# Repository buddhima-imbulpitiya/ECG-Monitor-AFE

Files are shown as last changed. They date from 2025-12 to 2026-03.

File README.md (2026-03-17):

# 3-Lead ECG Monitor - AFE

A fully functional analog front end (AFE) for an electrocardiogram (ECG) monitor designed and developed using exclusively analog electronics for signal acquisition, amplification, and filtering. The device captures cardiac electrical activity through three electrodes and outputs a clean ECG waveform for real-time monitoring on an oscilloscope.

<p align=>
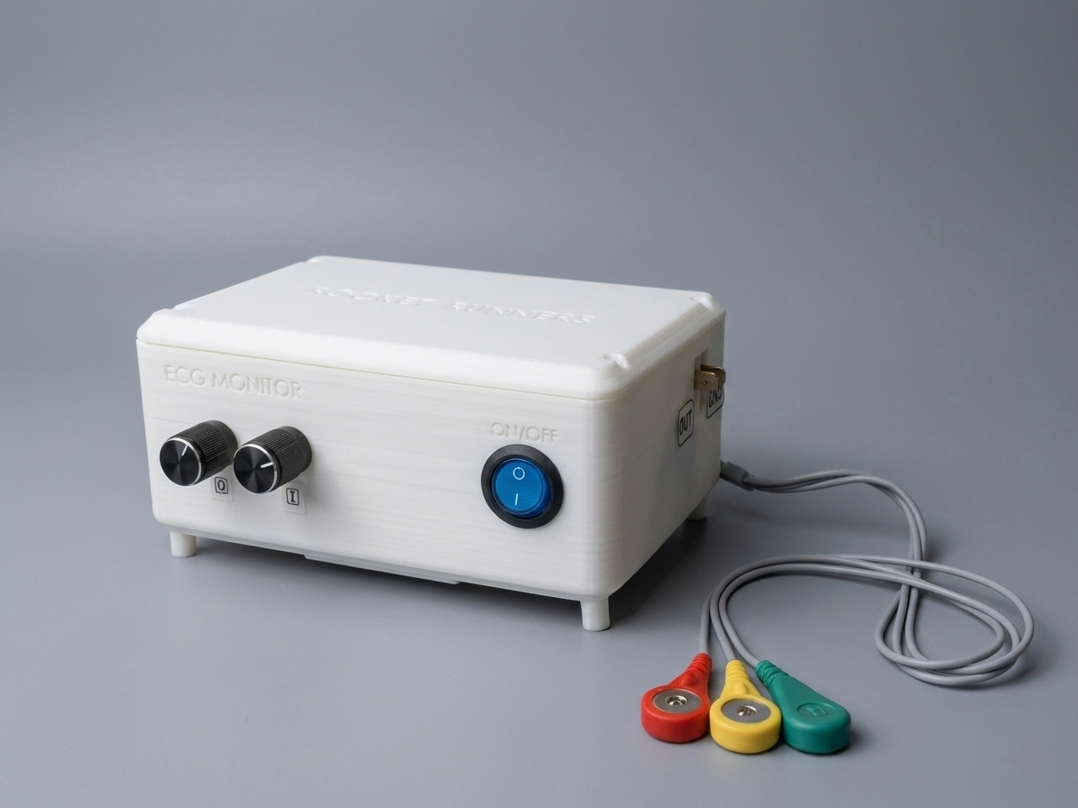
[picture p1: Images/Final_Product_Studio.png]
  
  &nbsp;&nbsp;&nbsp;&nbsp; &nbsp;&nbsp;&nbsp;&nbsp;&nbsp;&nbsp; &nbsp;&nbsp;&nbsp;&nbsp;&nbsp;&nbsp; &nbsp;&nbsp;&nbsp;&nbsp;&nbsp;&nbsp; &nbsp;&nbsp;&nbsp;
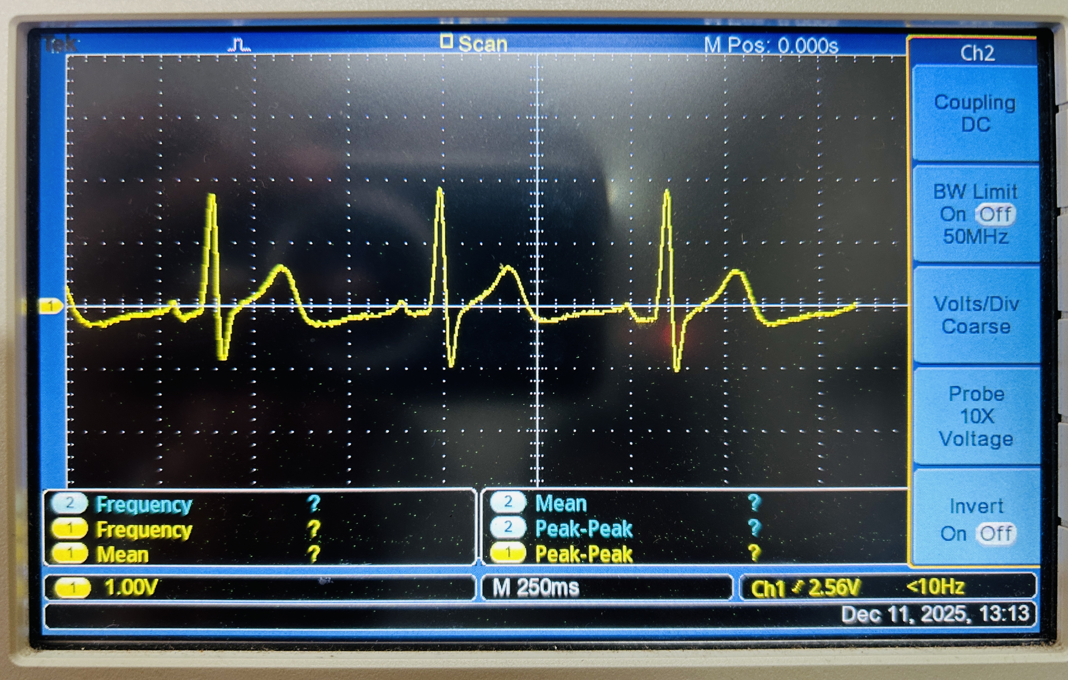
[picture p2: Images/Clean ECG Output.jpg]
  
<p/>
  
## 🔬 Overview

This project demonstrates the design and implementation of a 3-lead ECG monitoring system built entirely with analog components. The device safely extracts weak bioelectric signals from the human body (10 μV to 5 mV), amplifies them, and filters noise to produce a diagnostic-quality ECG waveform suitable for cardiac monitoring.

### Key Specifications

- **Signal Range**: 10 μV - 5 mV input amplitude
- **Frequency Range**: 0.5 Hz - 100 Hz (cardiac signal bandwidth)
- **Electrode Configuration**: 3-lead setup (LA, RA, RL) following Einthoven's Triangle (Lead-I)
- **Power Supply**: Battery-operated (dual 7.4V Li-Ion) for minimal powerline interference
- **Output**: Analog signal for oscilloscope display

## ✨ Features

- **High-Precision Instrumentation Amplifier**: OP07-based differential amplifier with adjustable gain and excellent CMRR (120 dB)
- **Multi-Stage Filtering**:
  - 2nd Order High-Pass Butterworth Filter (0.5 Hz cutoff) - removes baseline wander
  - 4th Order Low-Pass Butterworth Filter (100 Hz cutoff) - eliminates high-frequency noise
  - Wien-Robinson Notch Filter (50 Hz) - suppresses powerline interference
- **Right Leg Drive (RLD) Circuit**: Active common-mode rejection for enhanced noise immunity
- **Safety-First Design**: Battery-powered operation ensures patient safety
- **Custom PCB**: Professional PCB layout optimized for low-noise analog signal processing
- **3D-Printed Enclosure**: Ergonomic, portable design with proper electrode connections

### Signal Processing Stages

1. **Instrumentation Amplifier**: Extracts differential voltage between LA and RA electrodes with variable gain
2. **High-Pass Filter**: Removes DC offset and baseline wander (fc = 0.589 Hz)
3. **Low-Pass Filter**: Eliminates muscle artifacts and high-frequency interference (fc = 100 Hz)
4. **Notch Filter**: Attenuates 50 Hz powerline noise (fc = 49.8 Hz, Q = 0.67)
5. **Right Leg Drive**: Inverts and feeds back common-mode signals for active noise cancellation

## 🔨 Hardware Implementation

### PCB Design
- **Software**: EasyEDA
- **Type**: Through-hole components for cost effectiveness and ease of assembly
- **Layout**: 2-Layer optimized for minimal noise coupling and proper grounding

<p align=>
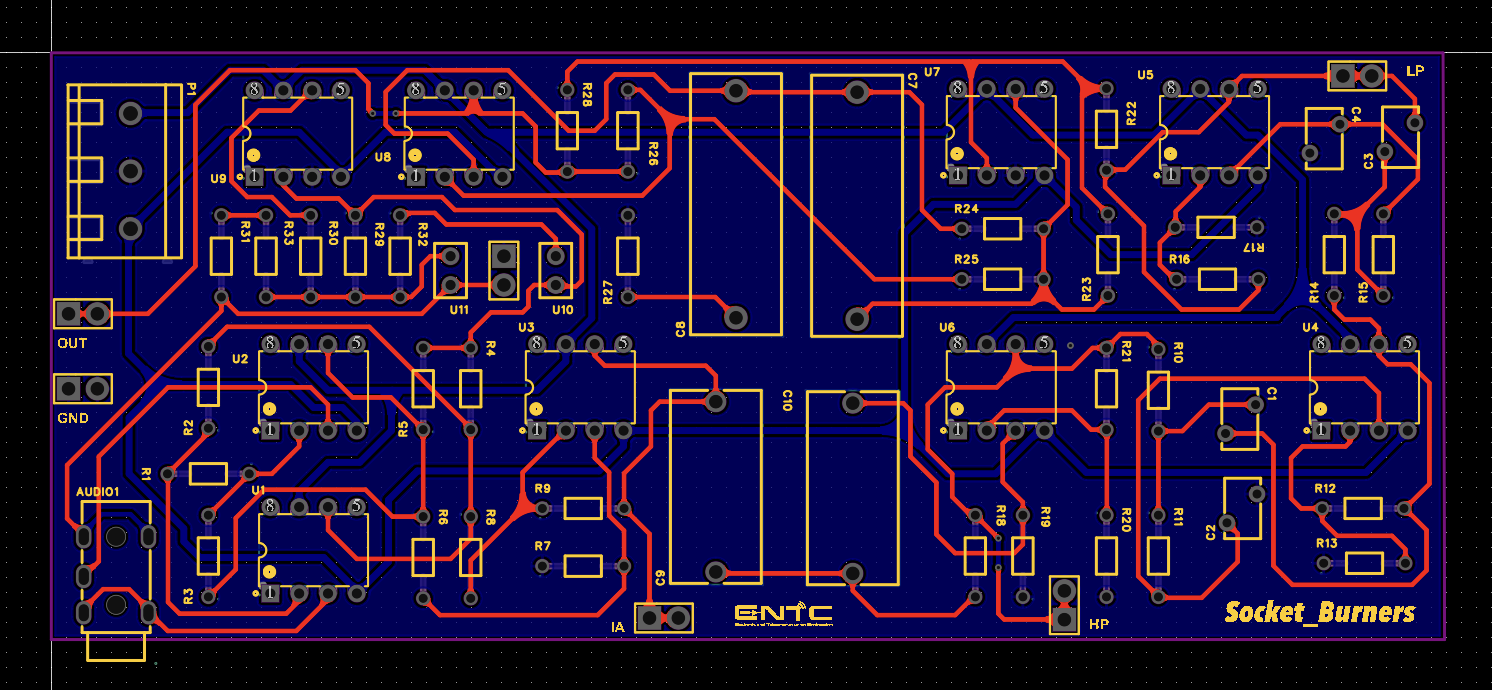
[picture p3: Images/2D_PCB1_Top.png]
  
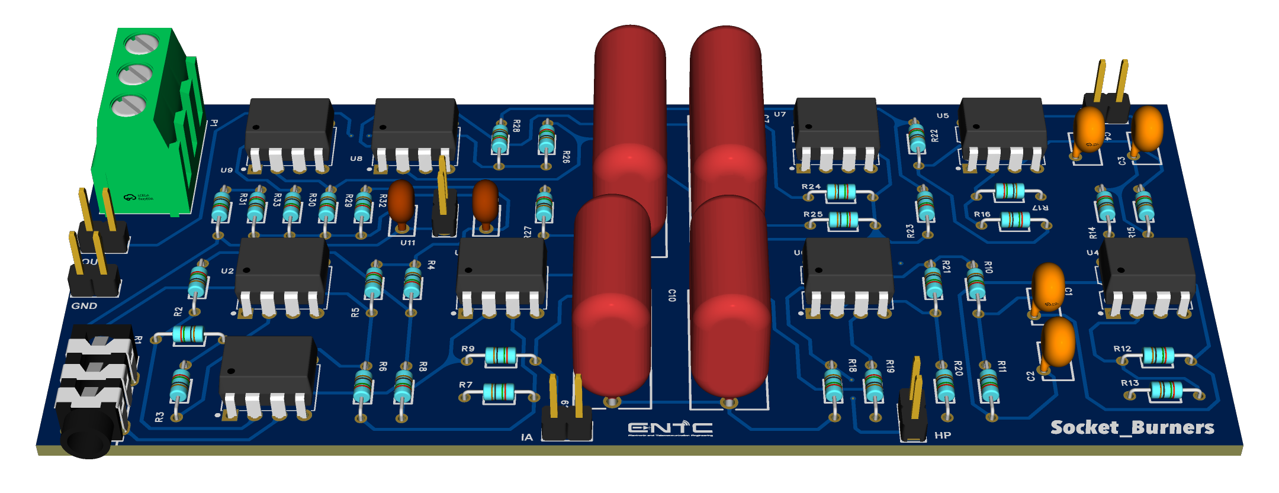
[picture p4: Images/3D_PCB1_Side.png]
  
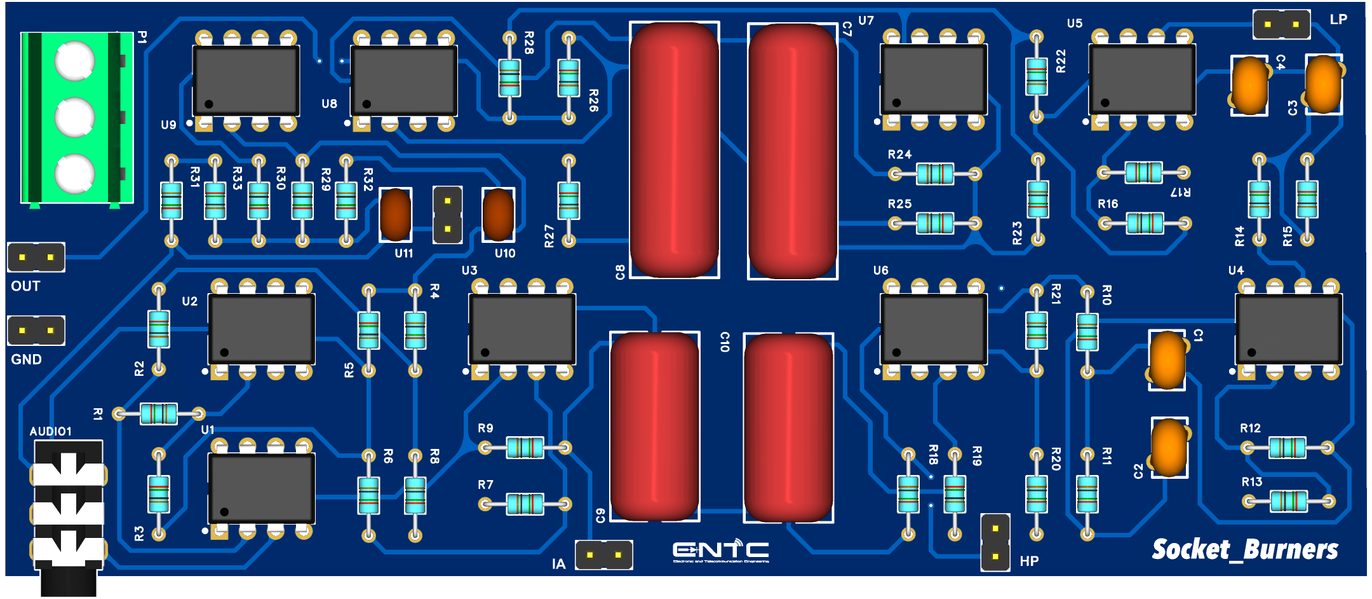
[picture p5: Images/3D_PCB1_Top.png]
   
<p/>
  
### Enclosure
- **Manufacturing**: 3D printed
- **Design**: Custom enclosure with cutouts for:
  - Output probes
  - Power switch
  - ECG leads
  - Potentiometer access for gain adjustment
    
 <p align=>
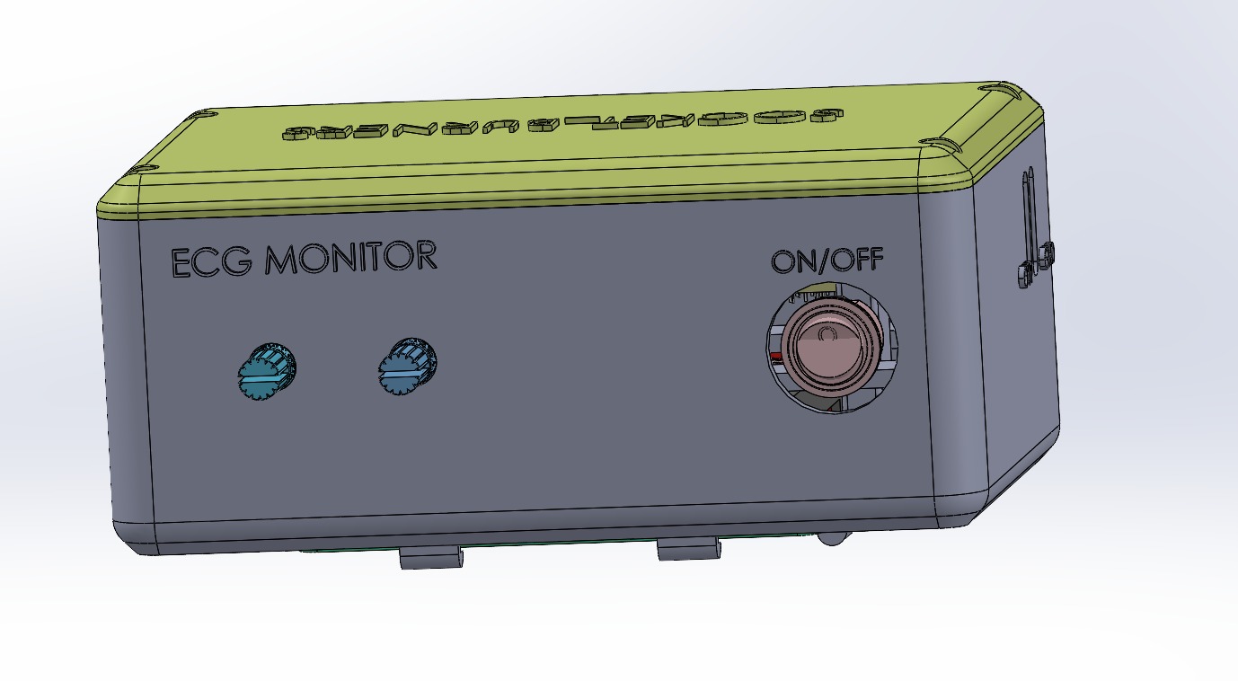
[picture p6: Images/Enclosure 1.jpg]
  
   &nbsp;&nbsp;&nbsp;&nbsp;
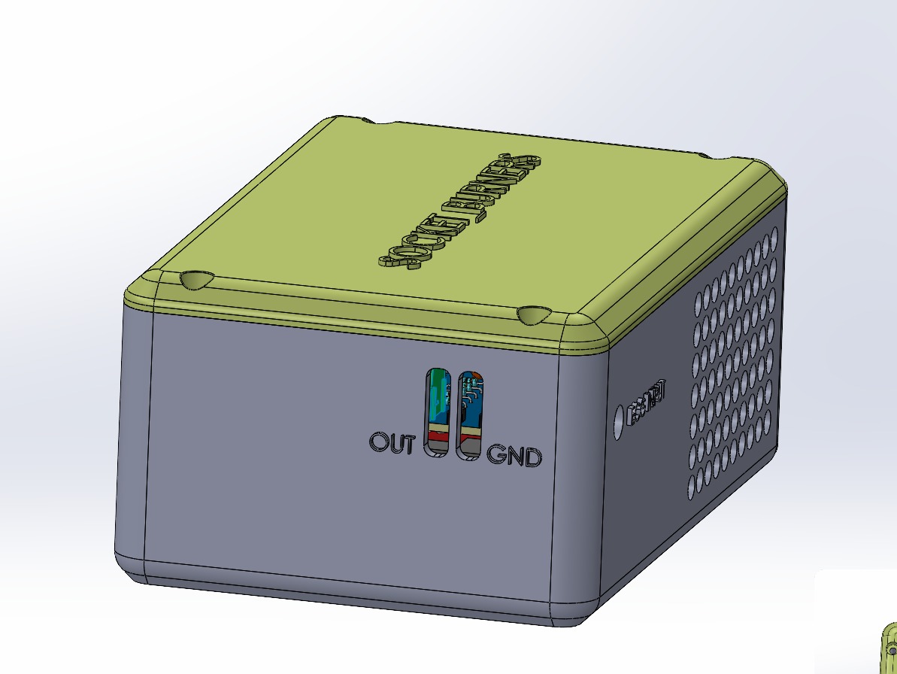
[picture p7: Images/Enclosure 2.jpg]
  
   &nbsp;&nbsp;&nbsp;&nbsp;
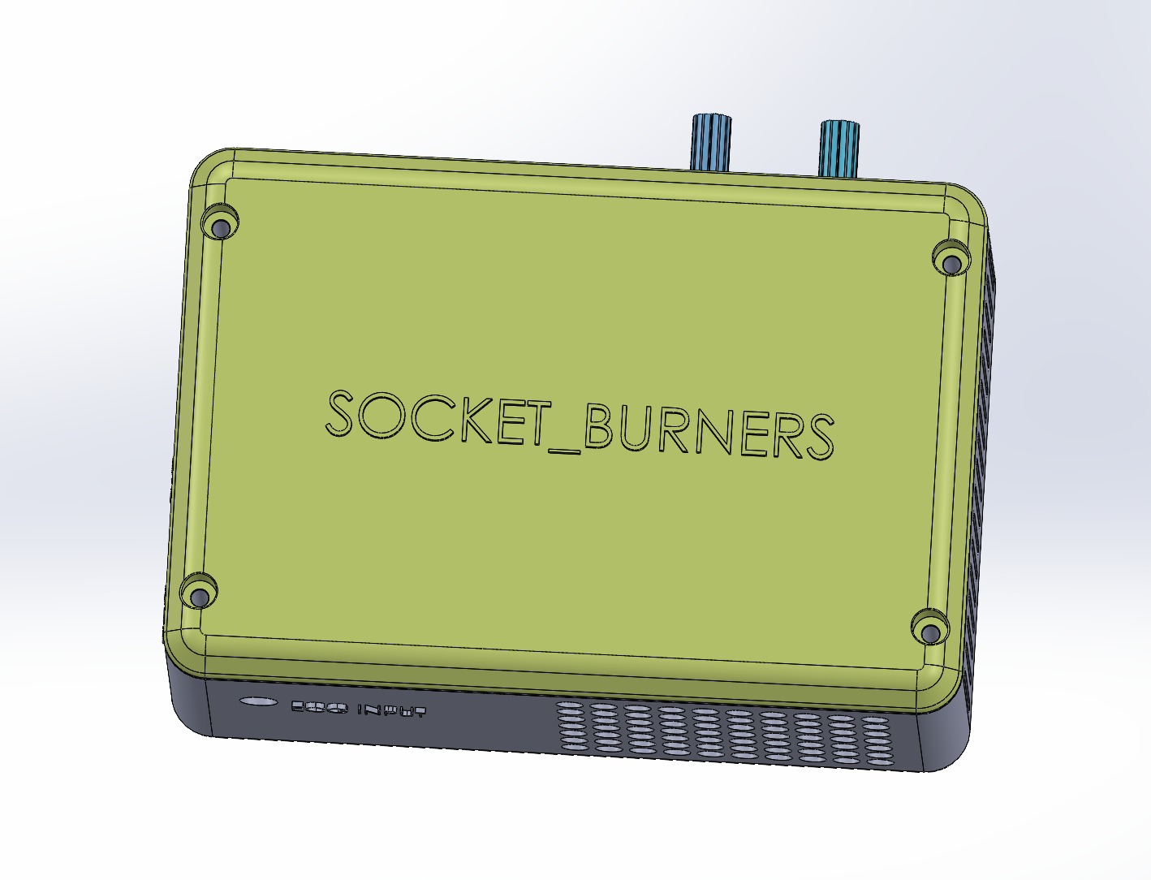
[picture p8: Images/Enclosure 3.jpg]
   
<p/>

## 📊 Testing Results

### Breadboard Prototype
- ✅ Successfully captured function generator ECG signals
- ✅ Verified with real human ECG signals
- ✅ Clean waveform with identifiable P, QRS, and T waves

<p align=>
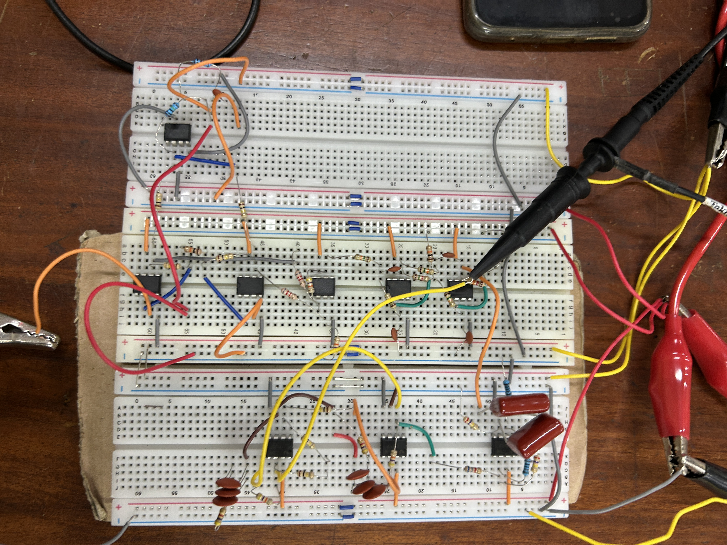
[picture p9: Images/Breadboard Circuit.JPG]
  
 &nbsp;&nbsp;&nbsp;
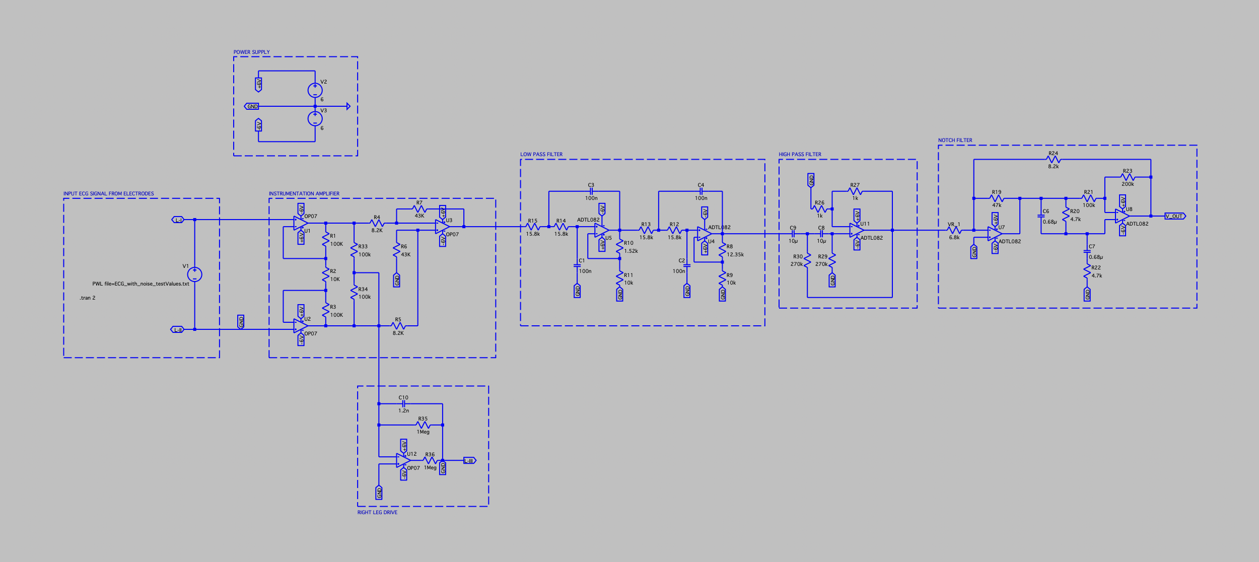
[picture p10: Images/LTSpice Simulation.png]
  
<p/>
<p align=>
  <em>Input ECG Waveform :</em>
  <br/>
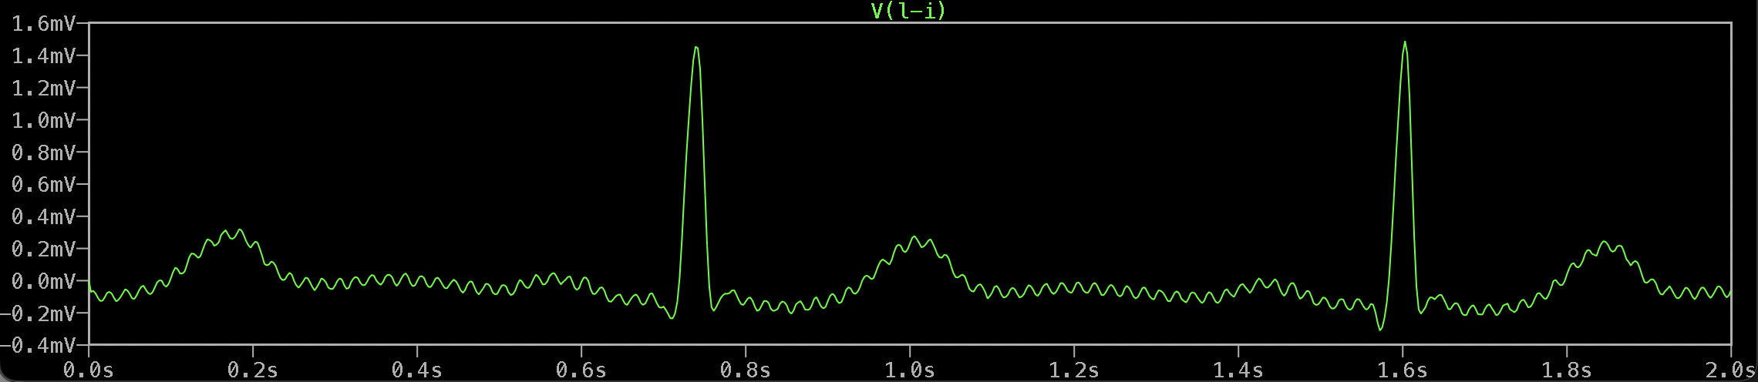
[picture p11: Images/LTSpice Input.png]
  

  <em>Output ECG Waveform :</em>
  <br/>
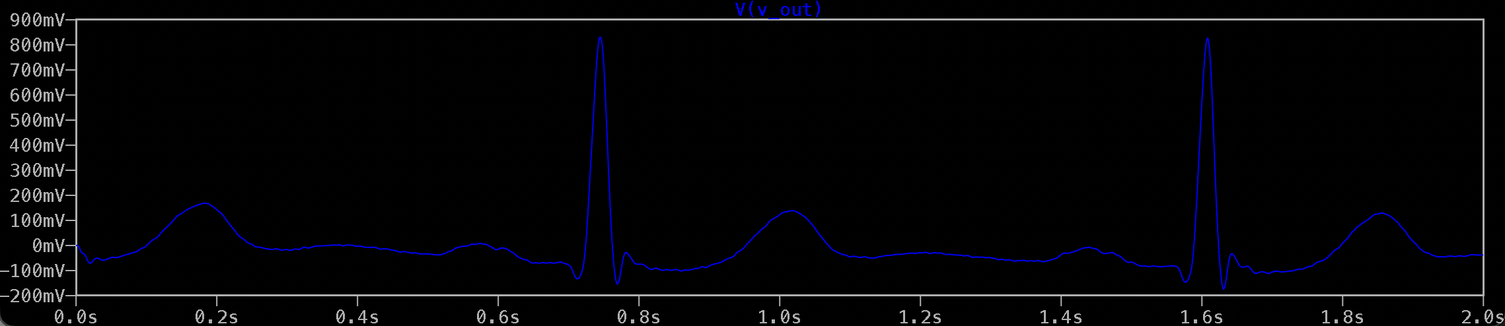
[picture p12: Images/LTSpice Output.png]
  

  <em>Overall Frequency Response :</em>
  <br/>
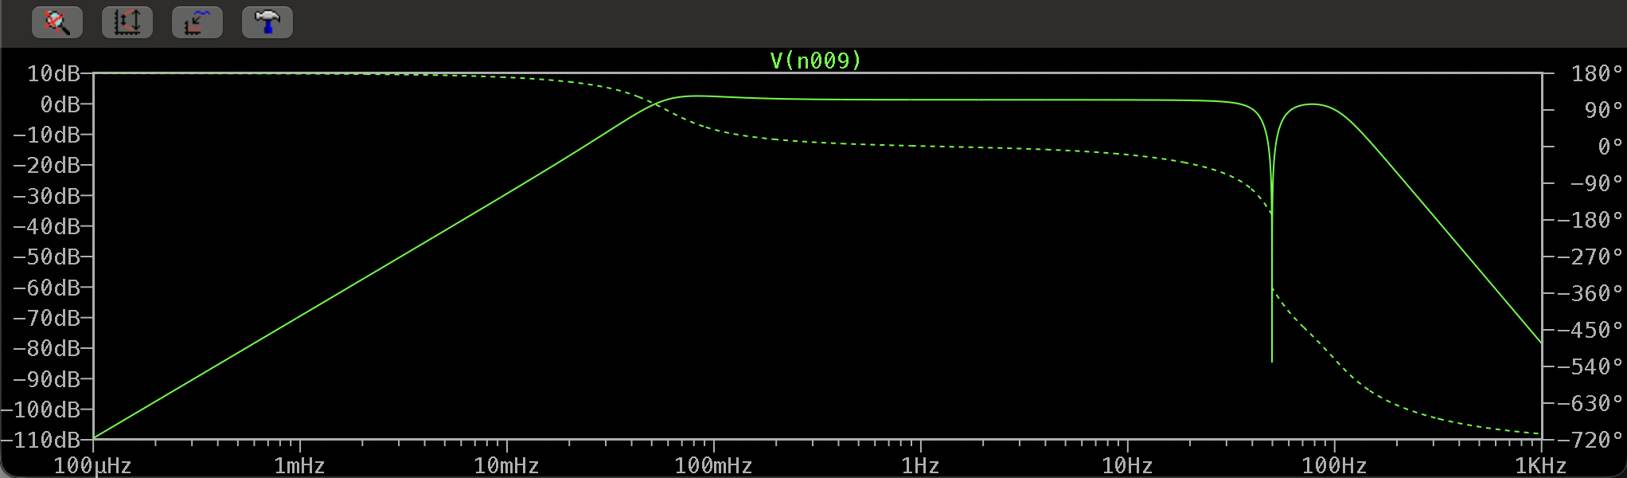
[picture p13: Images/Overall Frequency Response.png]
  

<p/>

### Final PCB Device
- ✅ Improved signal quality over breadboard implementation
- ✅ Reduced noise and interference
- ✅ Portable and user-friendly operation

<p align=>
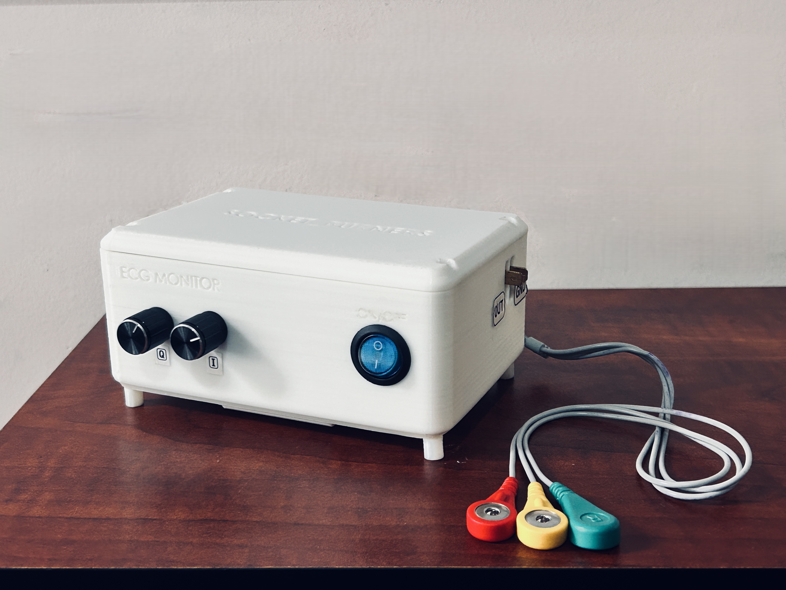
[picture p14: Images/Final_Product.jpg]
  
 &nbsp;&nbsp;&nbsp;&nbsp;&nbsp;&nbsp;&nbsp;&nbsp;&nbsp;&nbsp;&nbsp;&nbsp;&nbsp;&nbsp;&nbsp;&nbsp;&nbsp;&nbsp;&nbsp;&nbsp;&nbsp;&nbsp;&nbsp;&nbsp;&nbsp;&nbsp;&nbsp;&nbsp;
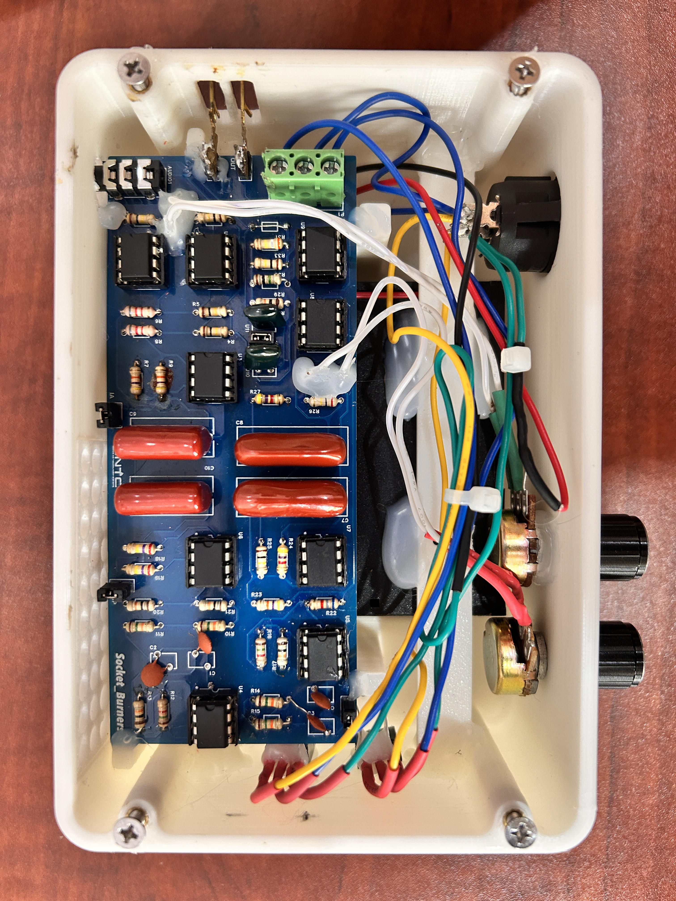
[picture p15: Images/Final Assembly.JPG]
  
<p/>

## 📁 Repository Structure

```
├── schematics/              # Circuit diagrams and design files
├── simulations/             # LTspice simulation files and results
├── pcb_design/              # KiCAD/Altium files, Gerber files, BoM
├── enclosure_design/        # 3D CAD models (.STL, .STEP files)
├── documentation/           # Project report, datasheets, calculations
├── testing/                 # Test results, oscilloscope captures
└── README.md               # This file
```

## 🚀 Getting Started

### Prerequisites
- PCB fabrication service (or equipment)
- Soldering equipment
- 3D printer (for enclosure)
- Standard ECG electrodes with 3.5mm connectors
- Oscilloscope for signal visualization
- 7.4V Li-Ion batteries (×4)

### Building the Device

1. **Clone the Repository**
   ```bash
   git clone https://github.com/yourusername/ecg-monitor.git
   cd ecg-monitor
   ```

2. **PCB Fabrication**
   - Navigate to `pcb_design/`
   - Send Gerber files to PCB manufacturer
   - Order components from BoM

3. **Assembly**
   - Solder components following the schematic
   - Test each stage individually before integration
   - Calibrate gain and notch filter potentiometers

4. **Enclosure**
   - Print enclosure from `enclosure_design/` files
   - Assemble PCB into enclosure
   - Connect battery pack and electrode leads

5. **Testing**
   - Use function generator with cardiac mode for initial testing
   - Test with real ECG signals
   - Adjust potentiometers for optimal signal quality

## 👥 Team SocketBurners

- [Buddhima Imbulpitiya](https://github.com/buddhima-imbulpitiya)
- [Oshan Imaduwage](https://github.com/oshan-imaduwage)
- [Malinda Illankoon](https://github.com/malindailankoon)
- [Manitha Ayanaja](https://github.com/ManiiAya)

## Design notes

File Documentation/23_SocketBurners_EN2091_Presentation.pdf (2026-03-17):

Introduction | Circuit Stage Design | Simulation Results | Testing Results | PCB | Enclosure

# Analog ECG Heart Monitor

# Team SocketBurners

# Analog Design Project

### University of Moratuwa

## December 13, 2025

Team SocketBurners | Analog ECG Heart Monitor | December 13, 2025 | 1 / 30

# 1 Introduction

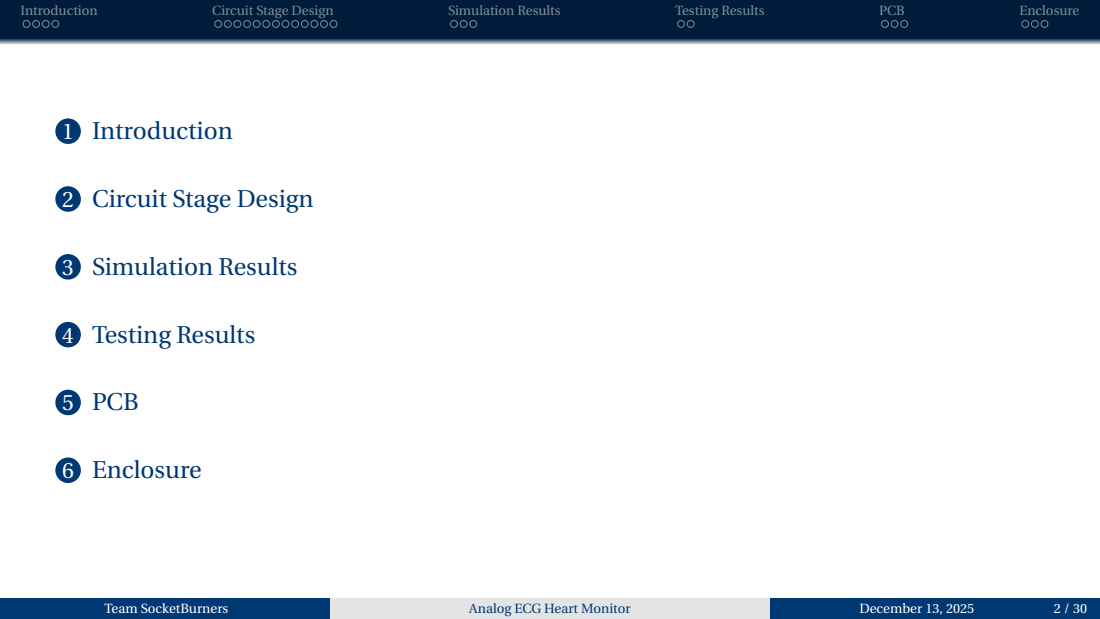
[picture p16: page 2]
3 Simulation Results; 4 Testing Results; 5 PCB; 6 Enclosure; Team SocketBurners; Analog ECG Heart Monitor; December 13, 2025

2 Circuit Stage Design

# 1 Introduction

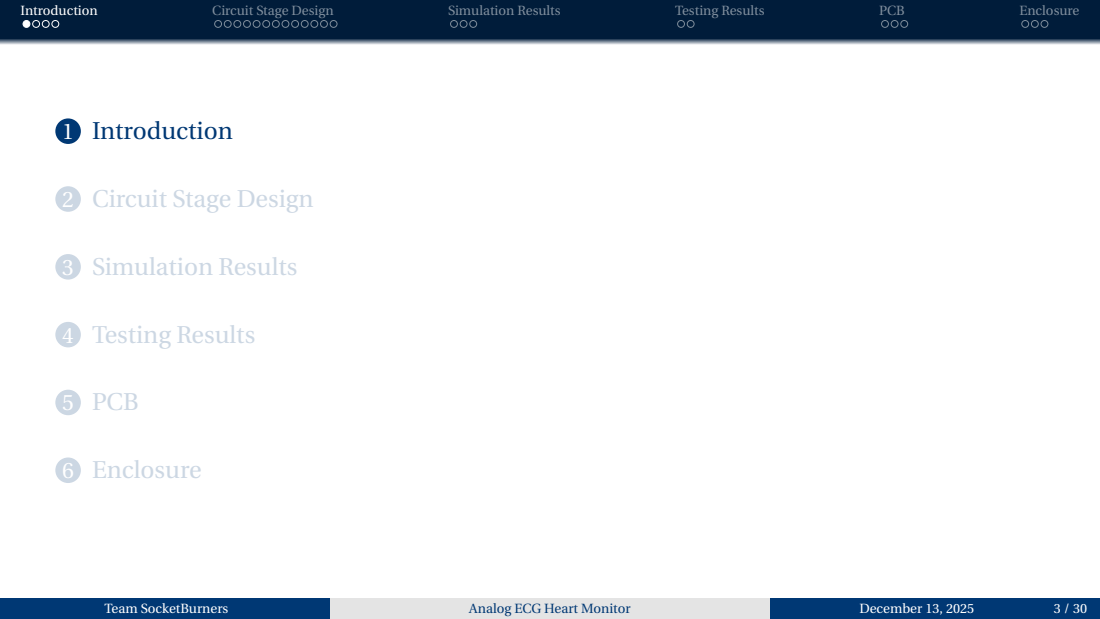
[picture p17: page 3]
3 Simulation Results; 4 Testing Results; 5 PCB; 6 Enclosure; Team SocketBurners; Analog ECG Heart Monitor; December 13, 2025

2 Circuit Stage Design

# What is an Electrocardiogram?

# - An Electrocardiogram (ECG) device is designed to display the electrical signals generated by the human cardiac system in real-time. It is a useful diagnosis tool for

many cardiac conditions.

# - The device takes inputs via 3 electrodes:

## - Left and Right Arm Electrodes (LA and RA), placed under the Left and Right clavicles - Right Leg Electrode (RL), placed on the hip or abdomen

# - The differential voltage signal between LA and RA is fed into the Instrumentation

Stage.

# - The Common Mode signal from the input is inverted and amplified via the Right

Leg Drive stage, fed back into the RL electrode.

# - The device must cleanly filter out noise and interference, without distorting the

biosignal input.

Team SocketBurners | Analog ECG Heart Monitor | December 13, 2025 | 4 / 30

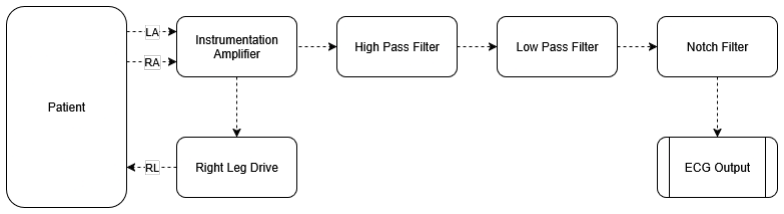
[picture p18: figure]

## Figure 1: Proposed System Architecture

Team SocketBurners | Analog ECG Heart Monitor | December 13, 2025 | 5 / 30

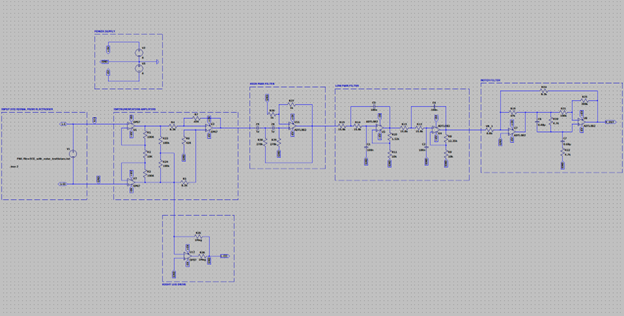
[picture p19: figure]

## Figure 2: Full Circuit Design (LTSpice Model)

Team SocketBurners | Analog ECG Heart Monitor | December 13, 2025 | 6 / 30

# 1 Introduction

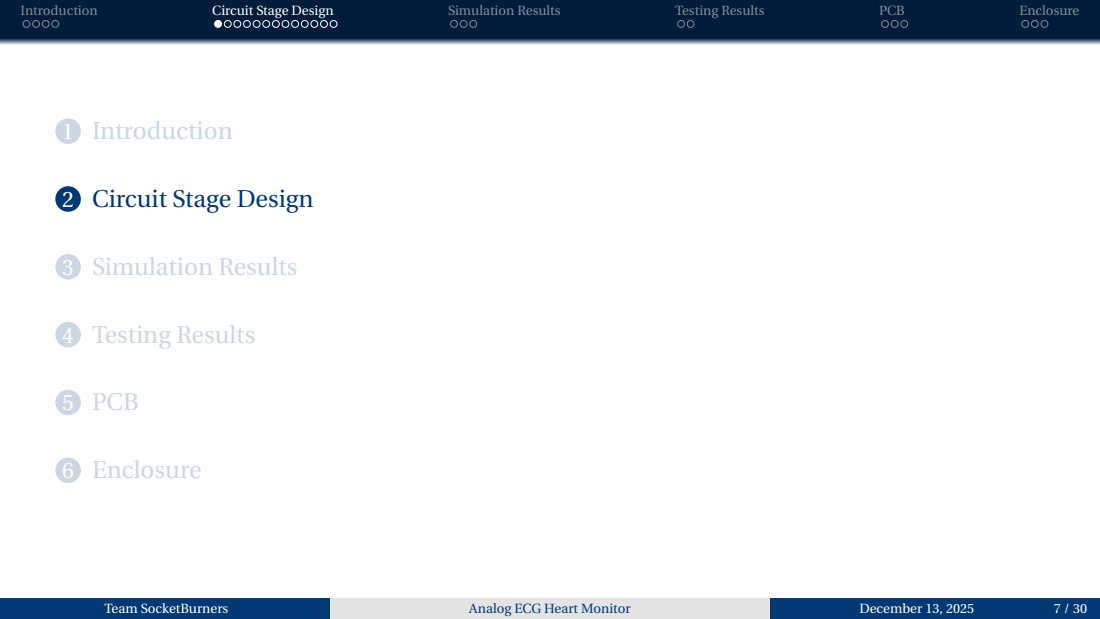
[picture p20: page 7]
3 Simulation Results; 4 Testing Results; 5 PCB; 6 Enclosure; Team SocketBurners; Analog ECG Heart Monitor; December 13, 2025

2 Circuit Stage Design

# The instrumentation amplifier extracts the differential voltage between two electrodes (LA and RA), and rejects any common-mode signals

such as noise or interference.

Av = (1+

2R

## Rgain

)×

R9
R4

# A potentiometer is used at R2 to allow for

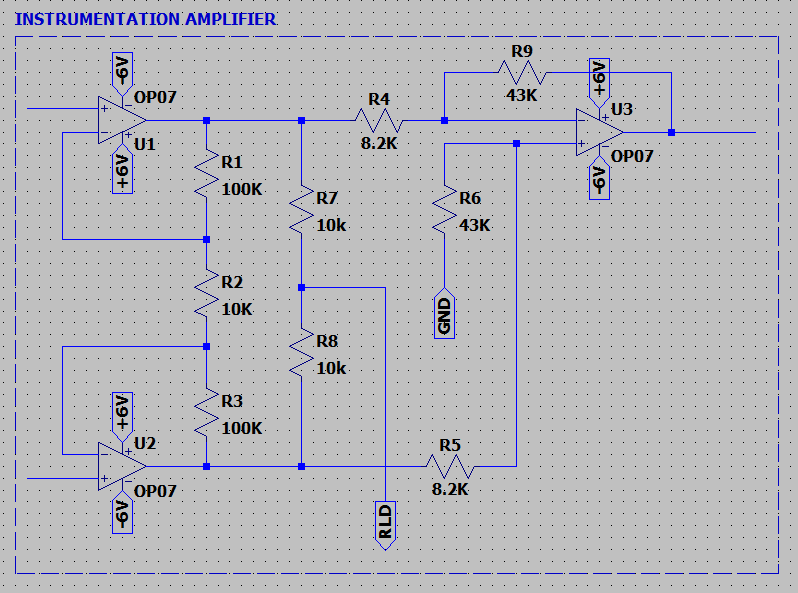
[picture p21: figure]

adjusting the gain. | Figure 3: Instrumentation Amplifier
| LTSpice Model
Team SocketBurners | Analog ECG Heart Monitor | December 13, 2025 | 8 / 30

# The High Pass Filter is used to remove baseline wander and low-frequency noise from the ECG signal. A 2nd-order Butterworth configuration was used, governed by the following equations:

# Cutoff Frequency: fc =

1
2π

p

# R1R2C1C2

(1)

# Gain: Av = 1+

R1
R2

(2)

# These relationships determine the cutoff frequency and voltage gain based on resistor and capacitor values. A cutoff around 0.5 Hz was targeted to minimize baseline drift

while preserving ECG signal components.

Team SocketBurners | Analog ECG Heart Monitor | December 13, 2025 | 9 / 30

## Using R3 = R2 = 1 kΩ, C1 = C2 = 1µF

fc =

1
2π

p

## R1R2C1C2

=

1
2π

√

## 270 kΩ×270 kΩ×1µF×1µF

= 0.589Hz

## Using R1 = R2 = 1 kΩ, C1 = C2 = 1µF

Av = 1+

R1
R2
= 1+

1 kΩ
1 kΩ

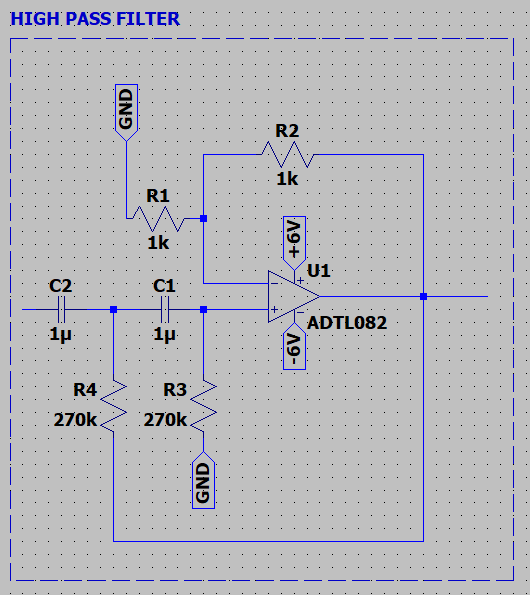
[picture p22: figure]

= 2 | Figure 4: High Pass Filter Simulation
Team SocketBurners | Analog ECG Heart Monitor | December 13, 2025 | 10 / 30

# The Low Pass Filter is used to remove unwanted high-frequency components caused by muscle artifacts and interference. A 4th-order Butterworth response was implemented using cascaded SallenKey stages. The governing setup equations are:

# Cutoff frequency: fc =

1

# 2πRC

# Closed-loop gain: Av = 1+

R1
R2

# Q-factor: Q =

1
3−K
Team SocketBurners | Analog ECG Heart Monitor | December 13, 2025 | 11 / 30

### Cutoff Frequency:

Using R = 15.8 kΩ, C = 100nF;

fc =

1

### 2πRC

=

1

### 2π×15.8 kΩ×100nF = 100.73Hz (≈ 100Hz)

### Gain Constants:

Using Rref = 10 kΩ;

K1 = 1+

R2

Rref

= 1+

1.52 kΩ
10 kΩ

= 1.152

K2 = 1+

R1

Rref

= 1+

12.35 kΩ
10 kΩ

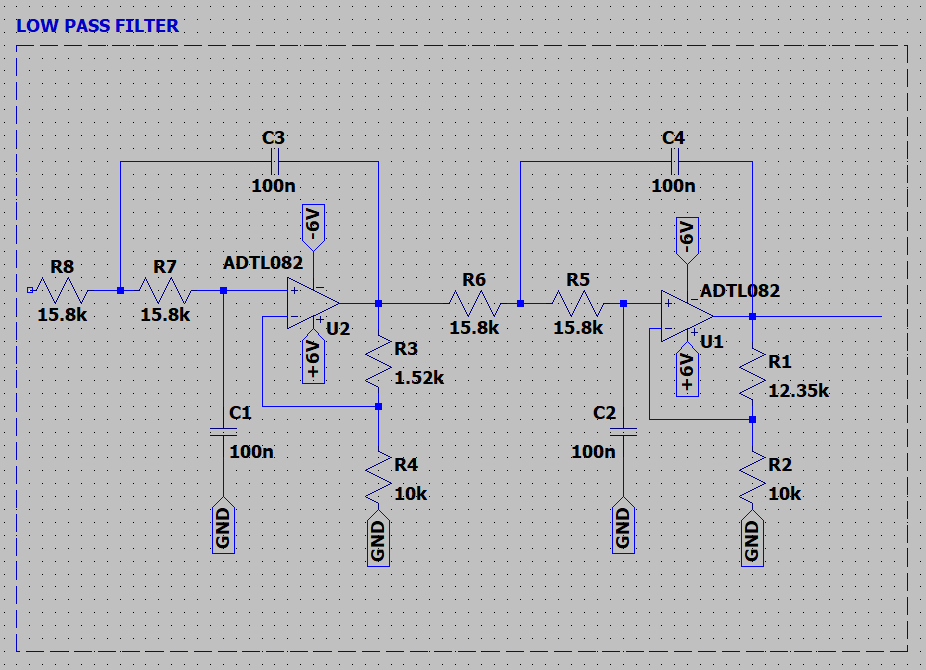
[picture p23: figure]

= 2.235 | Figure 5: Low-Pass Filter Simulation.
Team SocketBurners | Analog ECG Heart Monitor | December 13, 2025 | 12 / 30

## Using Q =

1
3−K

,

Q1 =

1
3−1.152
= 0.5411

Q2 =

1
3−2.235
= 1.307

## Table 1: Standard K-Values for Butterworth Filters

Order | K
2 | 1.586
4 | 1.152, 2.235
6 | 1.068, 1.586, 2.483
8 | 1.038, 1.337, 1.889, 2.610
Team SocketBurners | Analog ECG Heart Monitor | December 13, 2025 | 13 / 30

The Notch Filter is used to filter out the 50 Hz (or 60 Hz) mains interference and improve

# ECG SNR. A WienRobinson topology was chosen. The governing equations are:

# Cutoff frequency: fc =

1

# 2πRC

(3)

# Q-factor: Q =

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
# Gain: Av = −

R1
R2

·

1
3Q

(5)

Team SocketBurners | Analog ECG Heart Monitor | December 13, 2025 | 14 / 30

## Using R = 4.7 kΩ, C = 0.68µF

fc =

1

## 2πRC

=

1

## 2π×4.7 kΩ×0.68¸tF

= 49.8Hz

## Using R1 = 47 kΩ, R2 = 8.2 kΩ

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
47 kΩ
8.2 kΩ

)

= 2.244

Team SocketBurners | Analog ECG Heart Monitor | December 13, 2025 | 15 / 30

## Using R1 = 47 kΩ, R2 = 6.8 kΩ, Q =

2
3
Av = −

R1
R2

×

1
3Q
= −

47 kΩ
6.8 kΩ

×

1
3×2.244
= −1.02

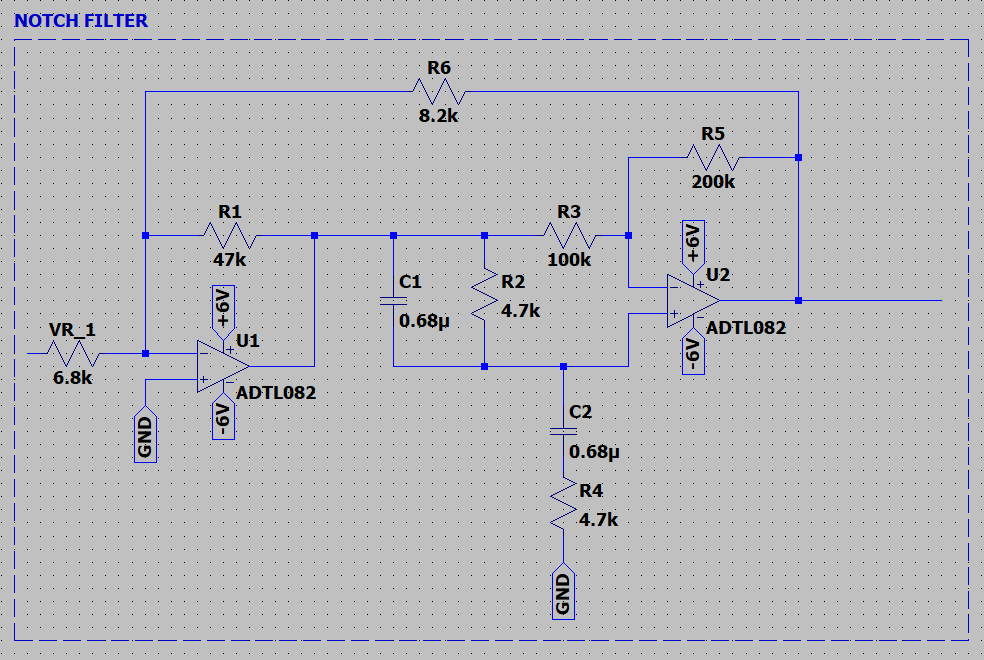
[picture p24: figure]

Figure 6: Notch Filter Simulation.

Team SocketBurners | Analog ECG Heart Monitor | December 13, 2025 | 16 / 30

# The Right Leg Drive (RLD) circuit senses the common-mode interference on the instrumentation amplifier inputs and inverts it before feeding it back into the body through the

right leg electrode.

# This feedback process effectively cancels out common-mode noise, thereby improving the Common-Mode Rejection Ratio (CMRR) of the

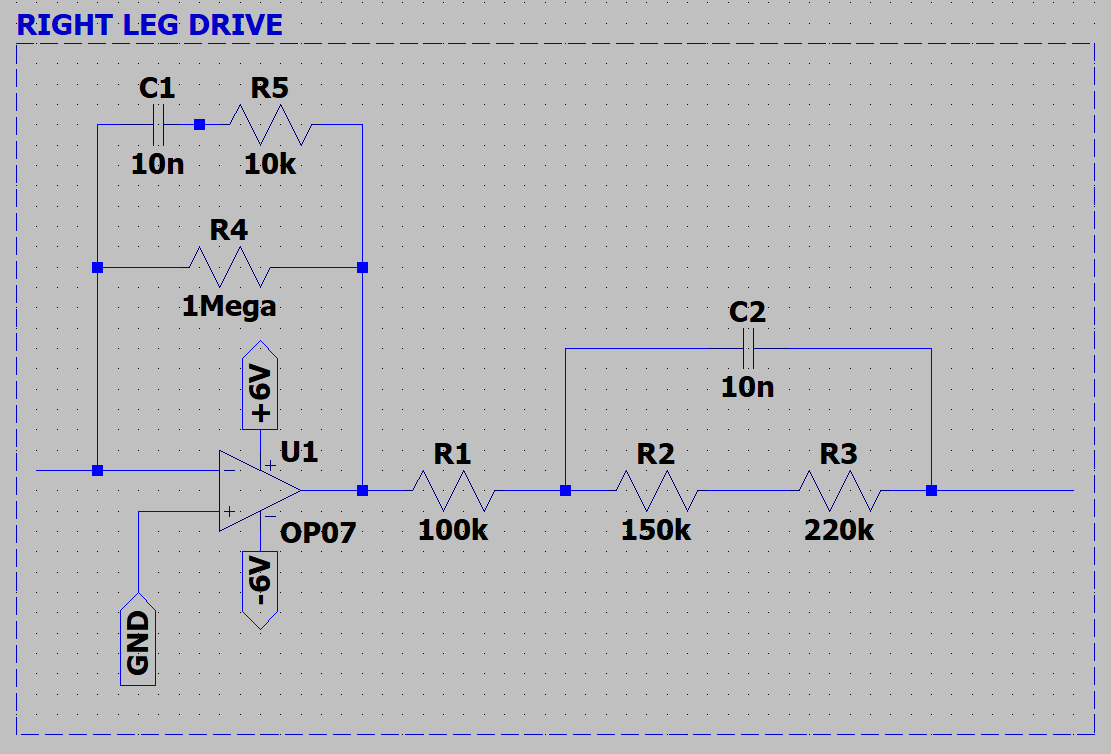
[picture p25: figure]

ECG front-end. | Figure 7: Right Leg Drive Simulation
Team SocketBurners | Analog ECG Heart Monitor | December 13, 2025 | 17 / 30

# The operational amplifiers require a split-rail power supply, generated via a simple circuit consisting of two 6 V batteries with a common

ground.

# Li-Ion batteries were chosen to reduce the impact of 50 Hz powerline noise on the received

ECG signal.

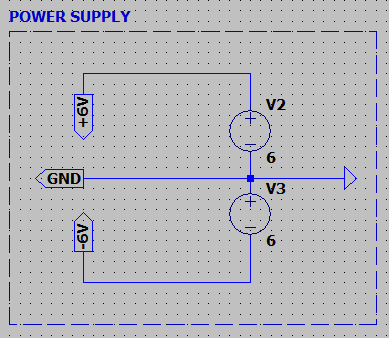
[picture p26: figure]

## Figure 8: Power Supply Simulation

Team SocketBurners | Analog ECG Heart Monitor | December 13, 2025 | 18 / 30

# In order to safely operate the device when turning on the ± Power Rails, a circuit using two

MOSFETs and a SPST switch was implemented.

# This allows for the disconnection of the two centre-tapped cells without risk of unwanted

discharging or damage to the device.

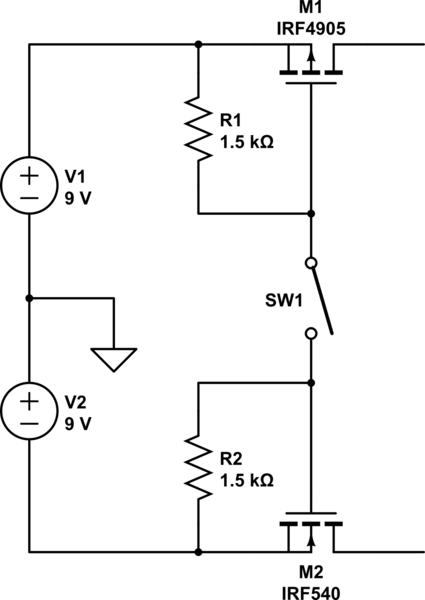
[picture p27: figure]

## Figure 9: Transistor Switch for Split Rail Power

Team SocketBurners | Analog ECG Heart Monitor | December 13, 2025 | 19 / 30

# 1 Introduction

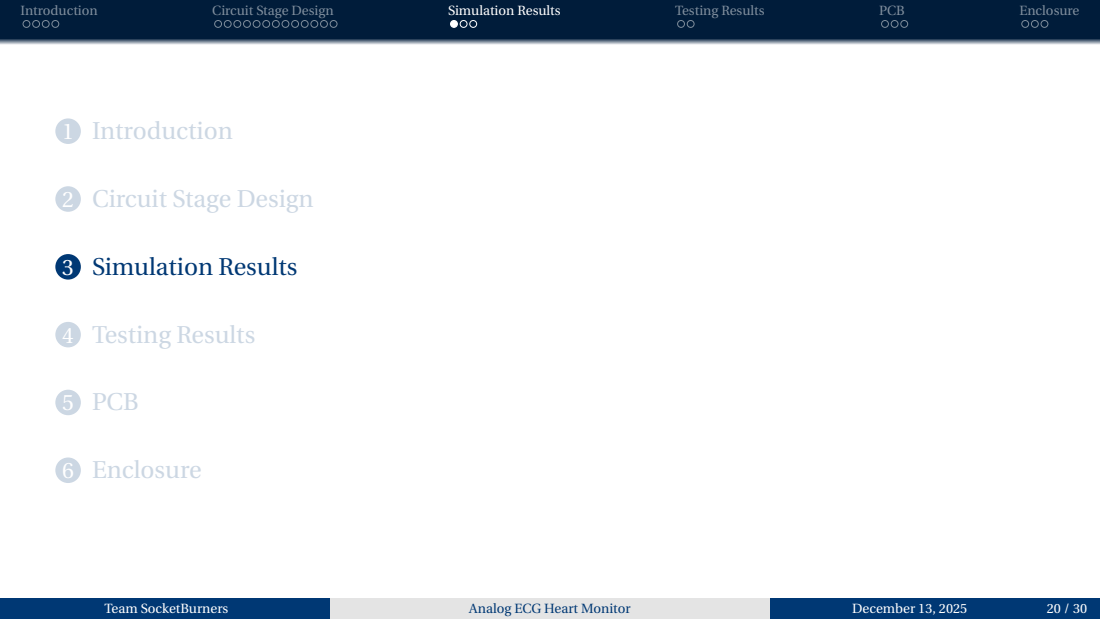
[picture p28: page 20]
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

2 Circuit Stage Design

# ECG Input vs Output

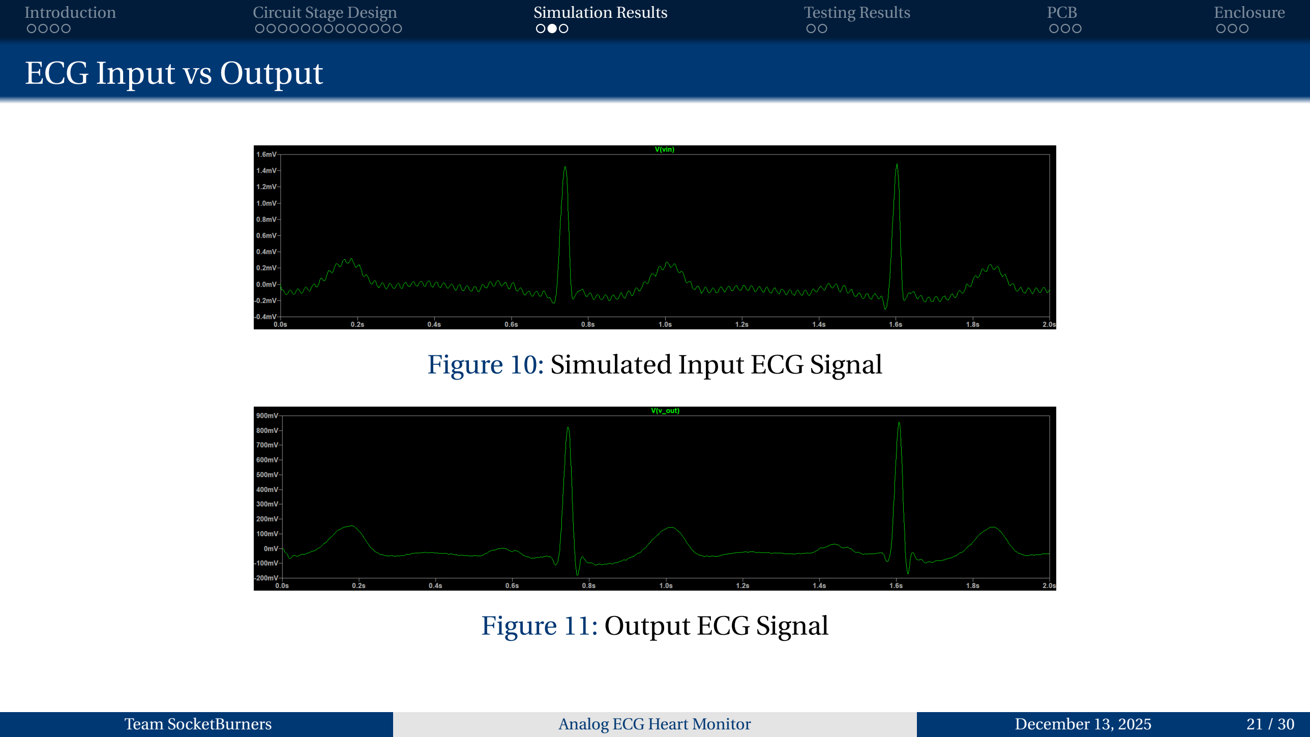
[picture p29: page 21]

## Figure 10: Simulated Input ECG Signal

## Figure 11: Output ECG Signal

Team SocketBurners | Analog ECG Heart Monitor | December 13, 2025 | 21 / 30

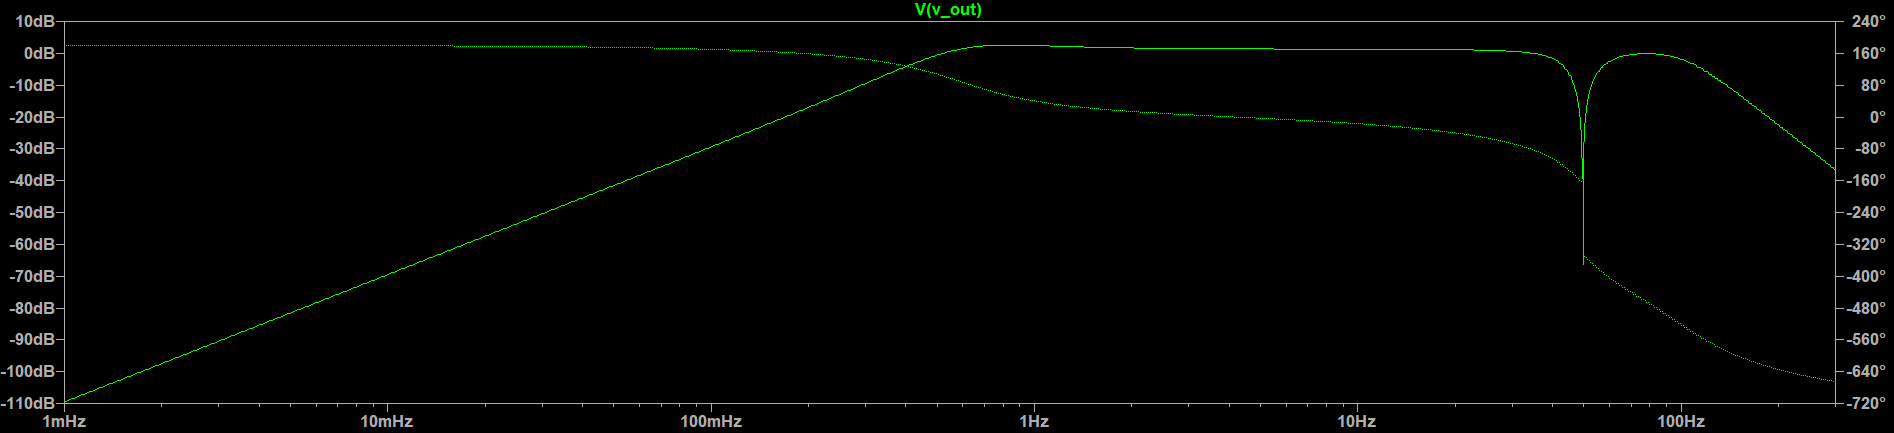
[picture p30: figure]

## Figure 12: Overall Frequency Response

Team SocketBurners | Analog ECG Heart Monitor | December 13, 2025 | 22 / 30

# 1 Introduction

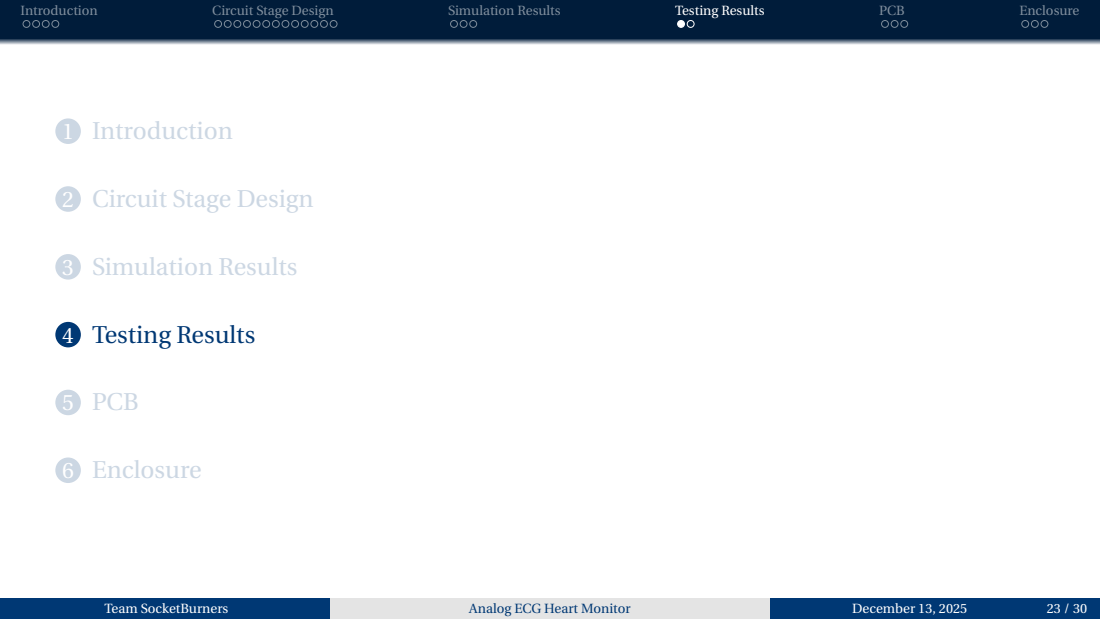
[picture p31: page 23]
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

2 Circuit Stage Design

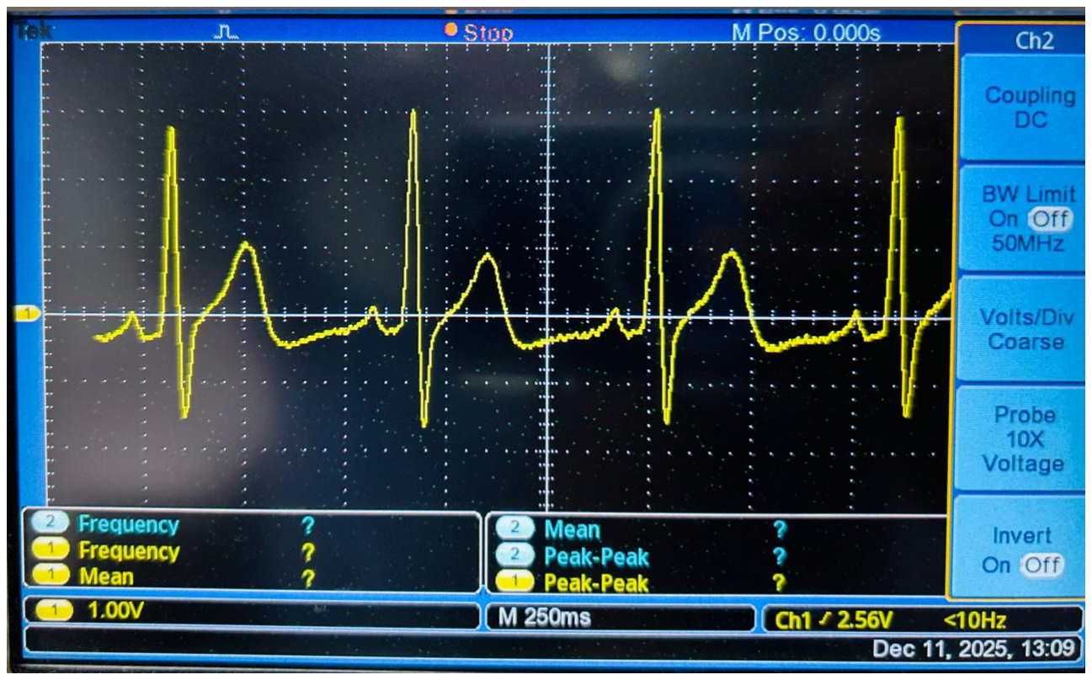
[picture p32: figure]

## Figure 13: Output Signal for the Real ECG

Team SocketBurners | Analog ECG Heart Monitor | December 13, 2025 | 24 / 30

# 1 Introduction

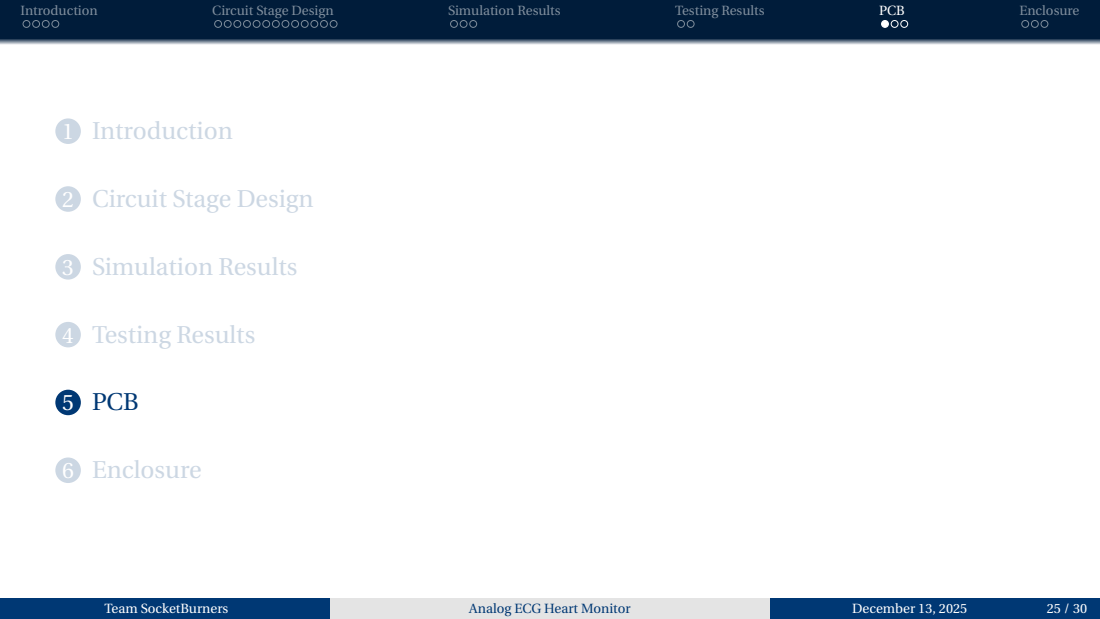
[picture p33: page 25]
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

2 Circuit Stage Design

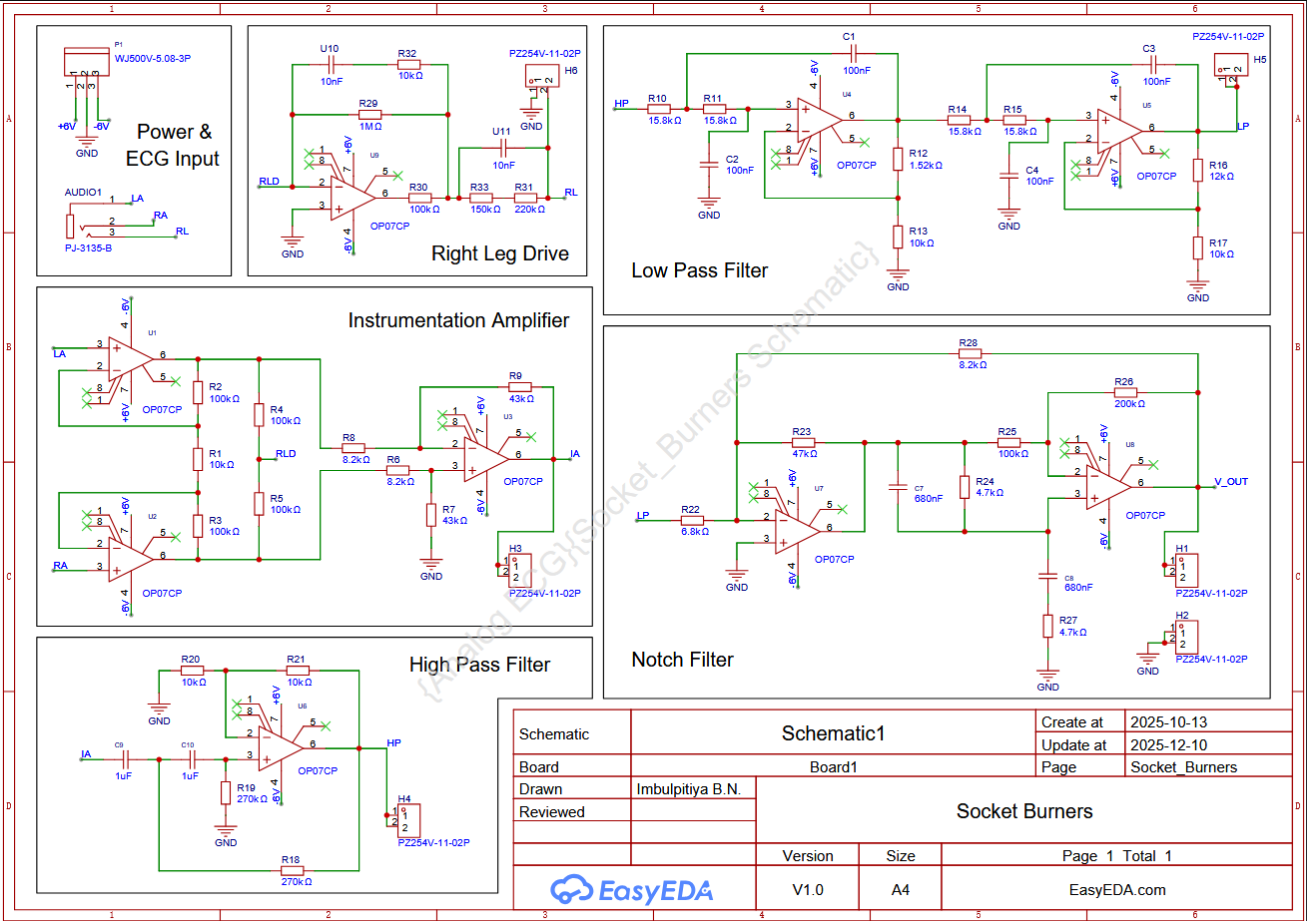
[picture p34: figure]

## Figure 14: Schematic Layout

Team SocketBurners | Analog ECG Heart Monitor | December 13, 2025 | 26 / 30

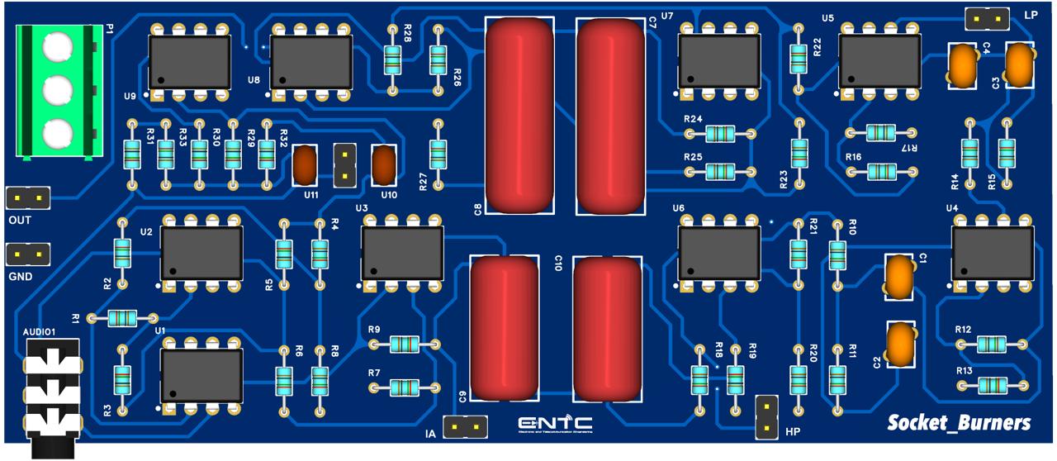
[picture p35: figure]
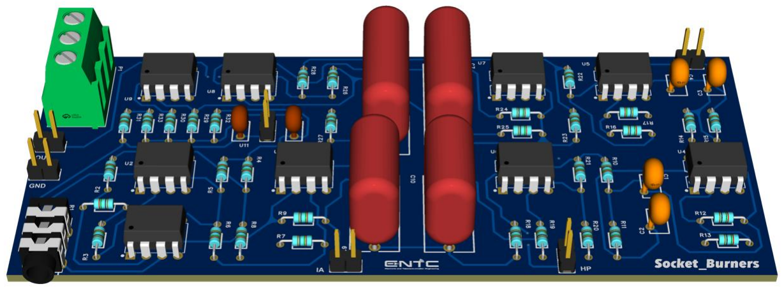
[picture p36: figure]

## Figure 15: PCB Layout: (a) Side View, (b) Top View, and (c) Angled View

Team SocketBurners | Analog ECG Heart Monitor | December 13, 2025 | 27 / 30

# 1 Introduction

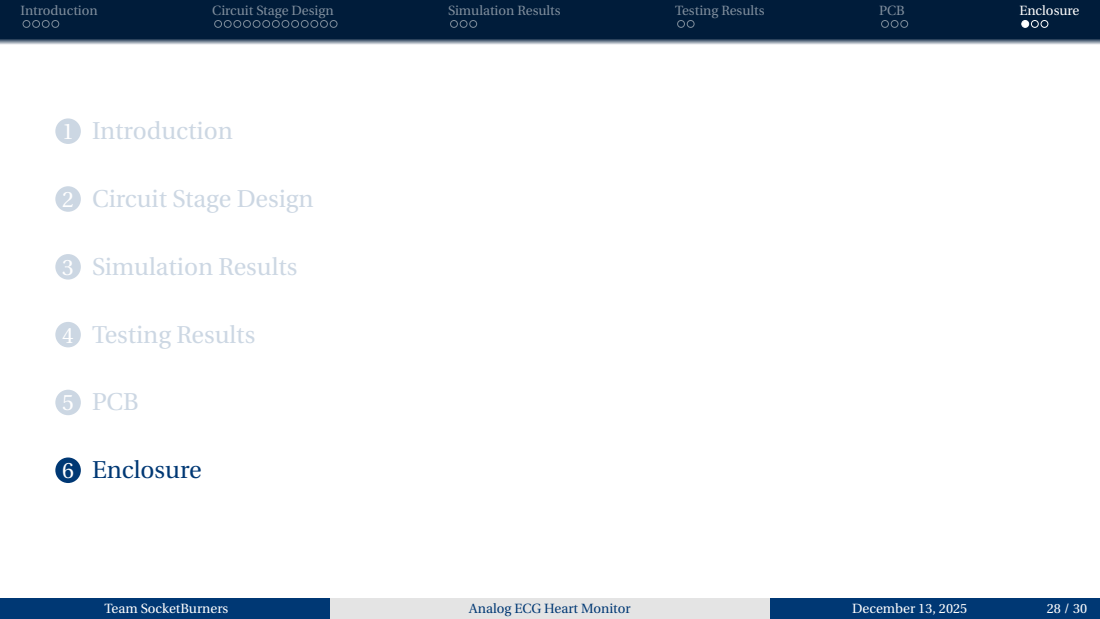
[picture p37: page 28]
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

2 Circuit Stage Design

# Enclosure 3D Model

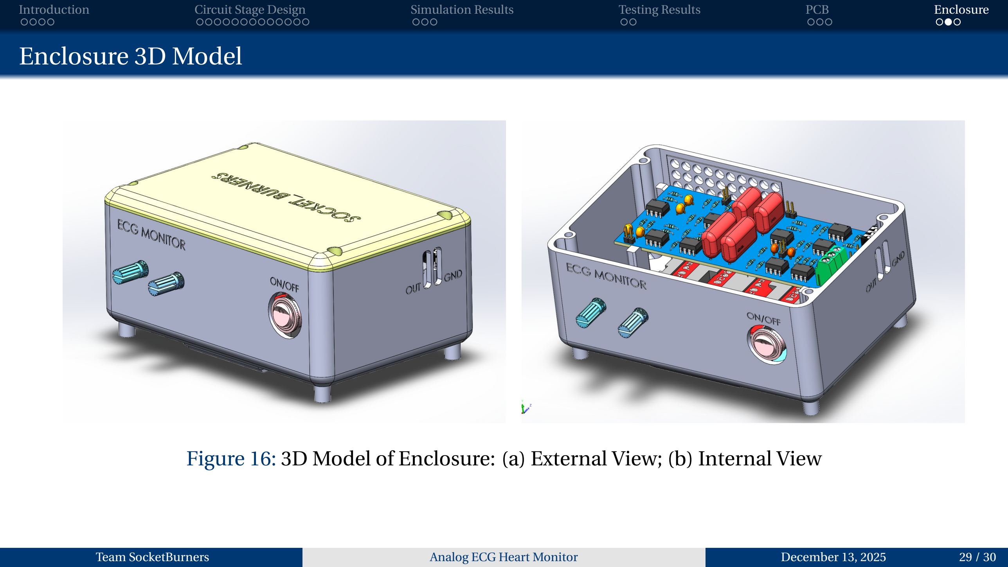
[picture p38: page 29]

## Figure 16: 3D Model of Enclosure: (a) External View; (b) Internal View

Team SocketBurners | Analog ECG Heart Monitor | December 13, 2025 | 29 / 30

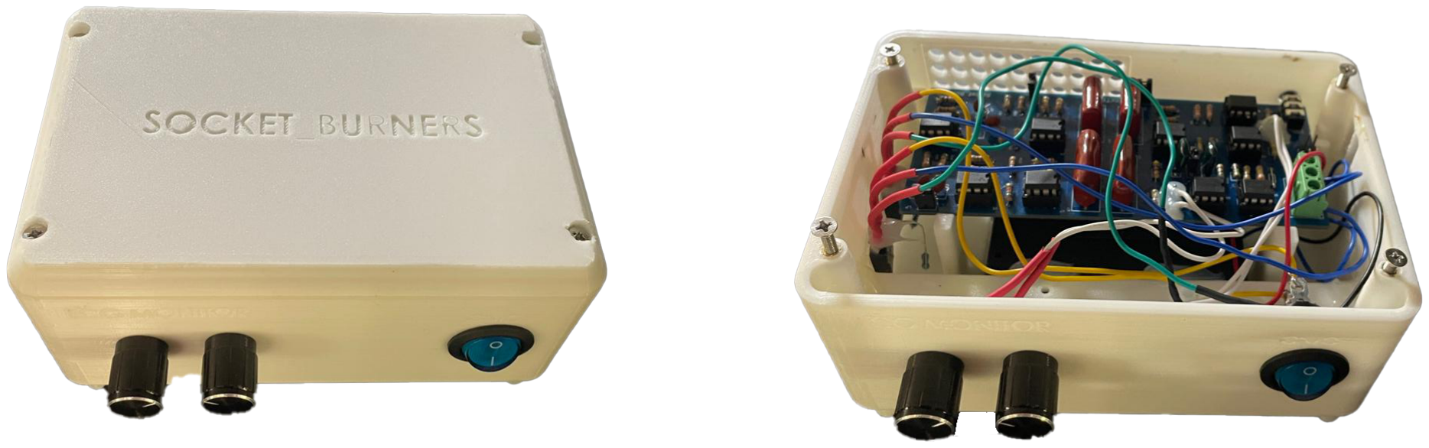
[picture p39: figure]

## Figure 17: Final Assembled Device: (a) External View; (b) Internal View

Team SocketBurners | Analog ECG Heart Monitor | December 13, 2025 | 30 / 30

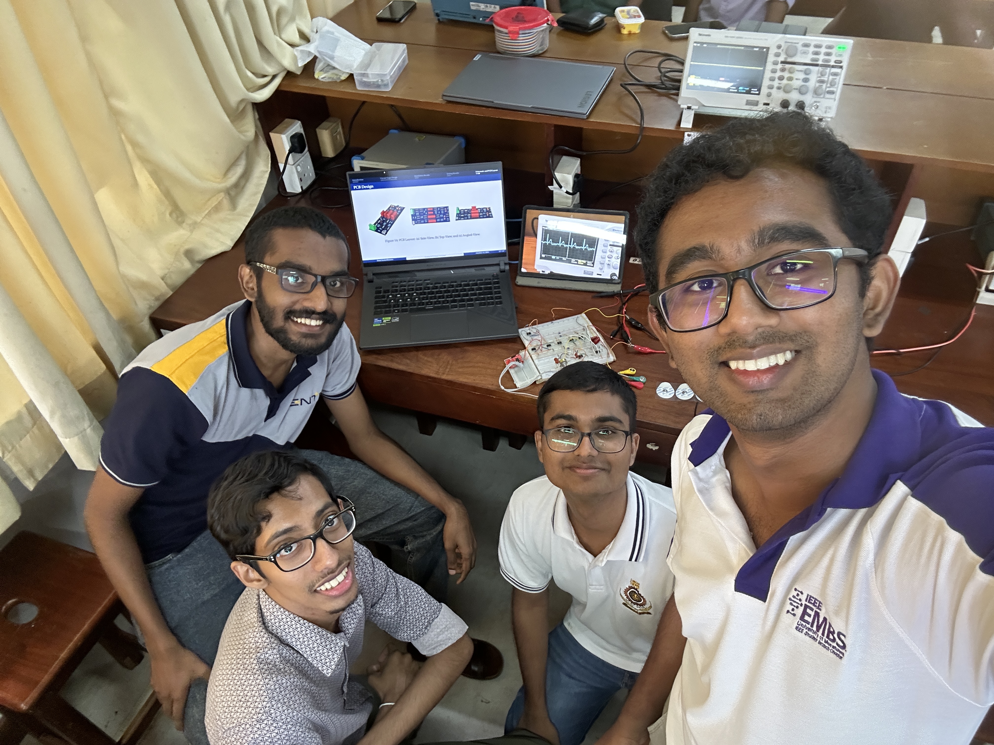
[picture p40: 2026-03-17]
Images/Team SocketBurners.JPG

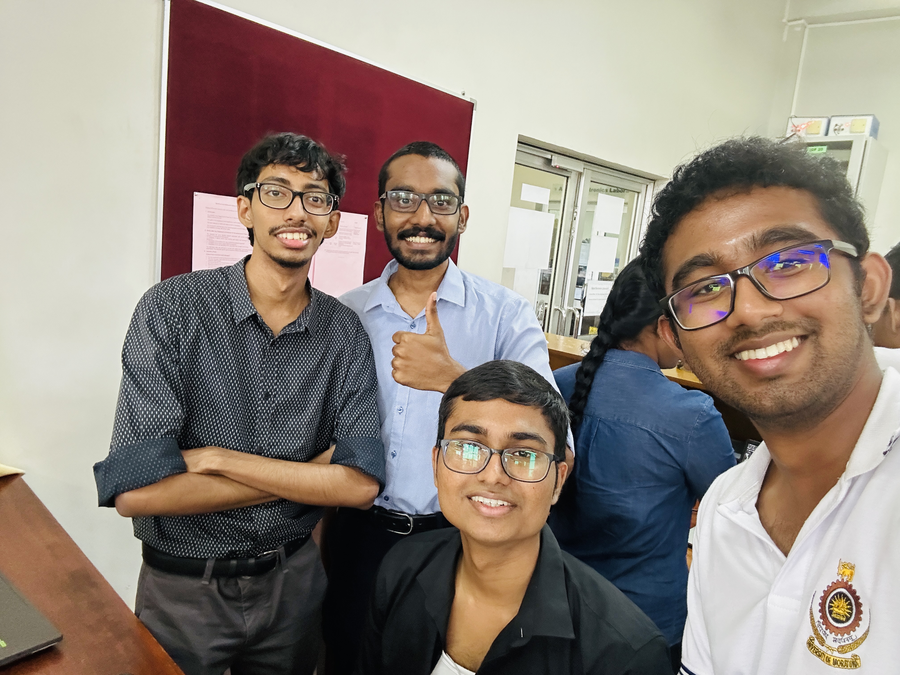
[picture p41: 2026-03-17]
Images/Team SocketBurners 2.jpg

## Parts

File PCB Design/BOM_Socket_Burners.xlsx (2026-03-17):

No. | Quantity | Comment | Designator | Footprint | Value | Manufacturer Part | Manufacturer | Supplier Part | Supplier
1 | 1 | PJ-3135-B | AUDIO1 | AUDIO-TH_PJ-3135-B |  | PJ-3135-B | XKB Connection(中国星坤) | C319112 | LCSC
2 | 4 | 100nF | C1,C2,C3,C4 | CAP-TH_L5.3-W3.2-P2.54-D0.6-S2.65 | 100nF | CC1H104ZA1ED3F5O1100 | Dersonic(德尔创) | C2761728 | LCSC
3 | 2 | 680nF | C7,C8 | CAP-TH_L23.0-W8.0-P20.00-D1.2 | 680nF | MPP684K2E2408158LC | SRD(圣融达) | C109858 | LCSC
4 | 2 | 1uF | C9,C10 | CAP-TH_L17.0-W8.0-P15.00-D1.2 | 1uF | KP105J2G1501 | KYET(科雅) | C390150 | LCSC
5 | 6 | PZ254V-11-02P | H1,H2,H3,H4,H5,H6 | HDR-TH_2P-P2.54-V-M |  | PZ254V-11-02P | XFCN(兴飞) | C492401 | LCSC
6 | 1 | WJ500V-5.08-3P | P1 | CONN-TH_3P-P5.00_WJ500V-5.08-3P |  | WJ500V-5.08-3P | KANGNEX(康奈克斯电气) | C72334 | LCSC
7 | 6 | 10kΩ | R1,R13,R17,R20,R21,R32 | RES-TH_BD1.8-L3.2-P7.20-D0.4 | 10kΩ
8 | 6 | 100kΩ | R2,R3,R4,R5,R25,R30 | RES-TH_BD1.8-L3.2-P7.20-D0.4 | 100kΩ
9 | 3 | 8.2kΩ | R6,R8,R28 | RES-TH_BD1.8-L3.2-P7.20-D0.4 | 8.2kΩ
10 | 2 | 43kΩ | R7,R9 | RES-TH_BD1.8-L3.2-P7.20-D0.4 | 43kΩ
11 | 4 | 15.8kΩ | R10,R11,R14,R15 | RES-TH_BD1.8-L3.2-P7.20-D0.4 | 15.8kΩ
12 | 1 | 1.52kΩ | R12 | RES-TH_BD1.8-L3.2-P7.20-D0.4 | 1.52kΩ
13 | 1 | 12kΩ | R16 | RES-TH_BD1.8-L3.2-P7.20-D0.4 | 12kΩ
14 | 2 | 270kΩ | R18,R19 | RES-TH_BD1.8-L3.2-P7.20-D0.4 | 270kΩ
15 | 1 | 6.8kΩ | R22 | RES-TH_BD1.8-L3.2-P7.20-D0.4 | 6.8kΩ
16 | 1 | 47kΩ | R23 | RES-TH_BD1.8-L3.2-P7.20-D0.4 | 47kΩ
17 | 2 | 4.7kΩ | R24,R27 | RES-TH_BD1.8-L3.2-P7.20-D0.4 | 4.7kΩ
18 | 1 | 200kΩ | R26 | RES-TH_BD1.8-L3.2-P7.20-D0.4 | 200kΩ
19 | 1 | 1MΩ | R29 | RES-TH_BD1.8-L3.2-P7.20-D0.4 | 1MΩ
20 | 1 | 220kΩ | R31 | RES-TH_BD1.8-L3.2-P7.20-D0.4 | 220kΩ
21 | 1 | 150kΩ | R33 | RES-TH_BD1.8-L3.2-P7.20-D0.4 | 150kΩ
22 | 9 | OP07CP | U1,U2,U3,U4,U5,U6,U7,U8,U9 | DIP-8_L9.6-W6.4-P2.54-LS7.6-BL-1 |  | OP07CP | TI(德州仪器) | C5224 | LCSC
23 | 2 | 10nF | U10,U11 | CAP-TH_L4.8-W2.8-P2.54-D0.7 | 10nF | CC1H102MA1EDB44B1100 | Dersonic(德尔创) |  | LCSC

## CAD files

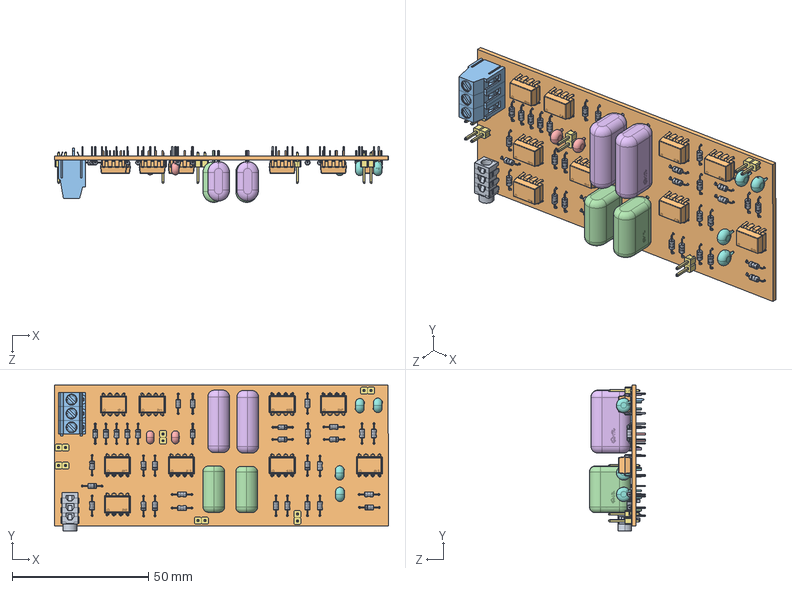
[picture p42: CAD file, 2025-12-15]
Enclosure Design/PCB.SLDASM
122.7 x 53.5 x 20.5 mm
RES-TH_BD1.8-L3.2-P7.20-D0.4~RES-TH_BD1.8-L3.2-P7.20-D0.4~LpO0.step x 33
DIP-8_L9.6-W6.4-P2.54-LS7.6-BL-1~DIP-8_L9.6-W6.4-P2.54-LS7.6-BL-1~LpO0.step x 9
CONN-TH_3P-P5.00_WJ500V-5.08-3P~CONN-TH_3P-P5.00_WJ500V-5.08-3P~LpO0.step
CAP-TH_L17.0-W8.0-P15.00-D1.2~CAP-TH_L17.0-W8.0-H14.0-P15.0~LpO0.step x 2
CAP-TH_L4.8-W2.8-P2.54-D0.7~CAP-TH_L4.8-W2.8-P2.54-D0.7~LpO0.step x 2
CAP-TH_L23.0-W8.0-P20.00-D1.2~CAP-TH_L23.0-W8.0-H14.5-P20.0~LpO0.step x 2
HDR-TH_2P-P2.54-V-M~HDR2.54-M-LI-1X2P~LpO0.step x 6
CAP-TH_L5.3-W3.2-P2.54-D0.6-S2.65~CAP-TH_L5.3-W3.2-P2.54-D0.6-S2.65~LpO0.step x 4
AUDIO-TH_PJ-3135-B~AUDIO-TH_PJ-3135-B~LpO0.step
Board~LpO0.step

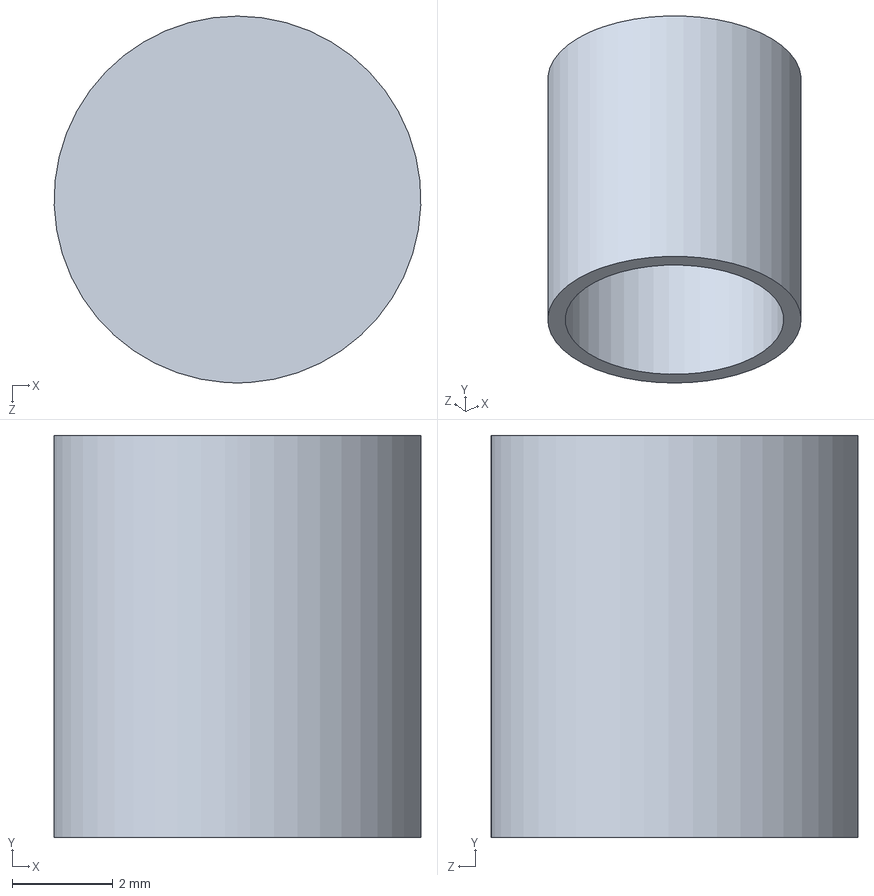
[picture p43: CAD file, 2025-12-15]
Enclosure Design/Part Files/LEG.SLDPRT
7.30 x 8.00 x 7.30 mm

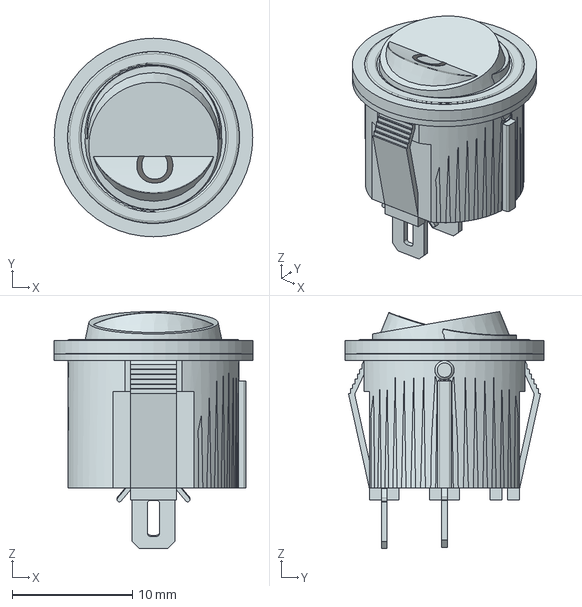
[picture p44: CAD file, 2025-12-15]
Enclosure Design/Step Files/Wippschalter_klein.stp
16.5 x 16.5 x 19.7 mm
Wippschalter_Wippe
Litze_FS x 2

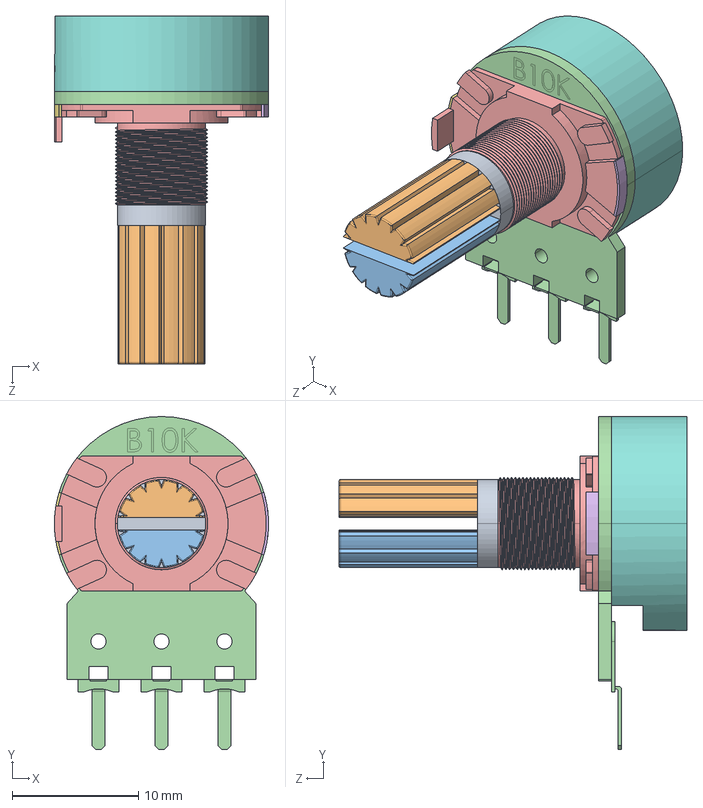
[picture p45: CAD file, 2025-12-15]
Enclosure Design/Step Files/PotentiometerB10K.STEP
17.0 x 26.4 x 27.6 mm

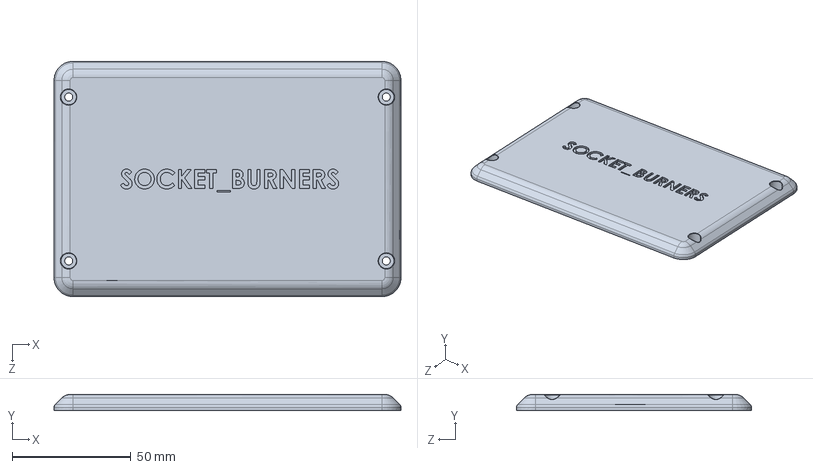
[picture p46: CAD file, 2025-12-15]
Enclosure Design/Part Files/LID.SLDPRT
146.0 x 6.79 x 99.0 mm

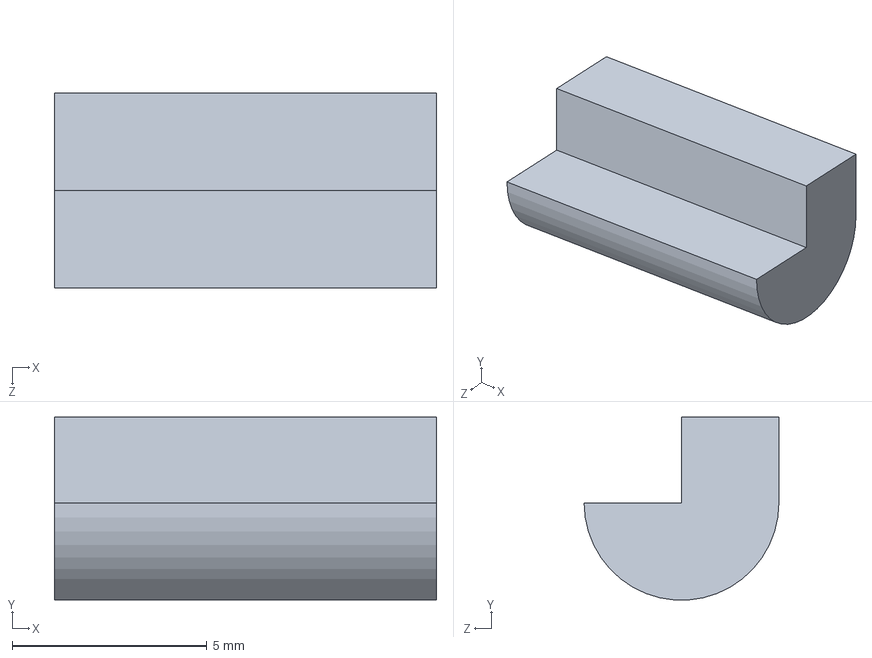
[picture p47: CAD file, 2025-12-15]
Enclosure Design/Part Files/HOOK2.SLDPRT
9.80 x 4.69 x 5.00 mm

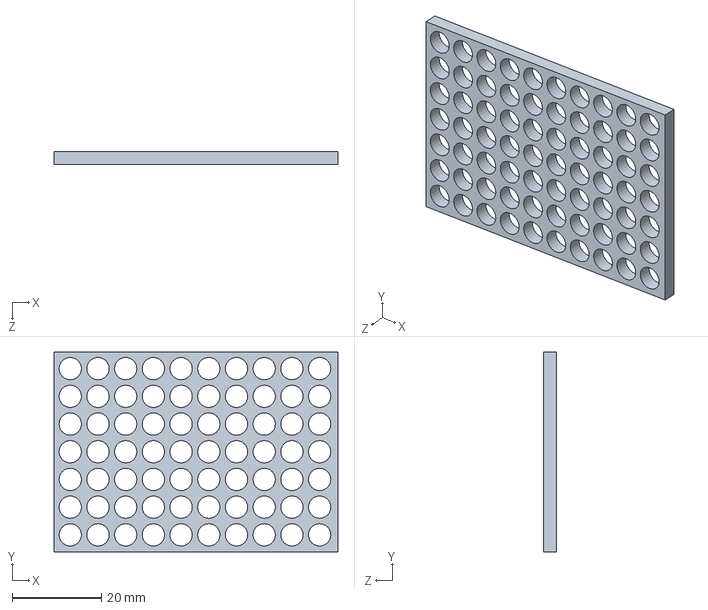
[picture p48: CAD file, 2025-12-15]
Enclosure Design/Part Files/CIRCLE WALL DESIGN.SLDPRT
63.5 x 44.7 x 3.00 mm

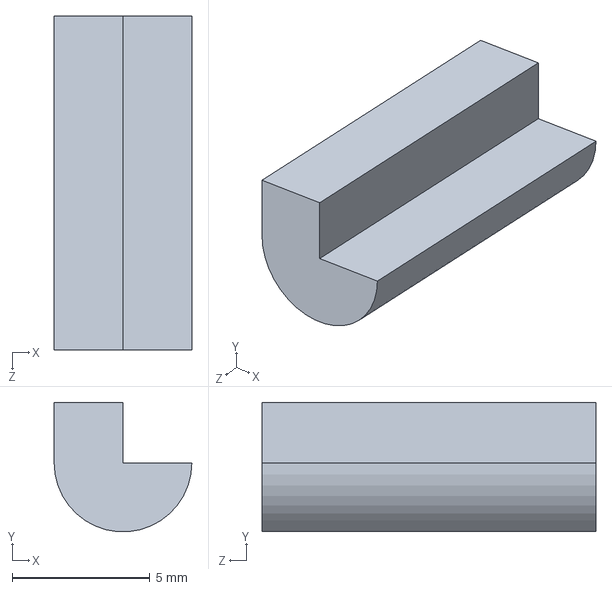
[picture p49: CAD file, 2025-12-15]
Enclosure Design/Part Files/HOOK1.SLDPRT
5.00 x 4.69 x 12.1 mm

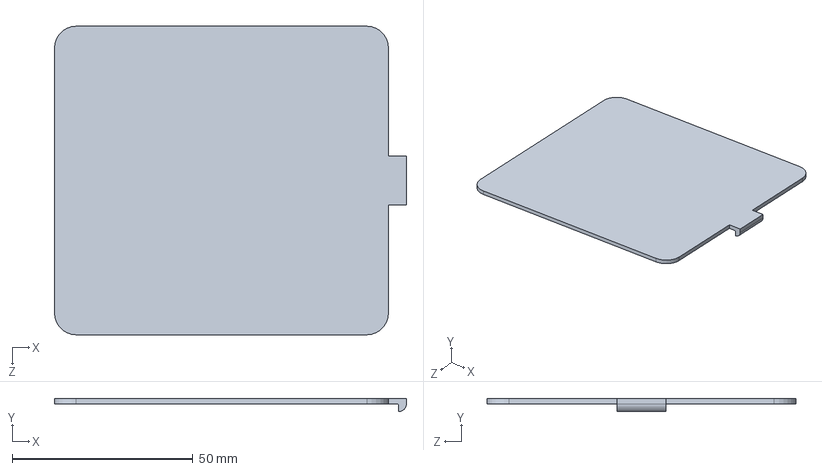
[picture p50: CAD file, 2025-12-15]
Enclosure Design/Part Files/BOTTOM LID.SLDPRT
97.5 x 3.67 x 85.5 mm

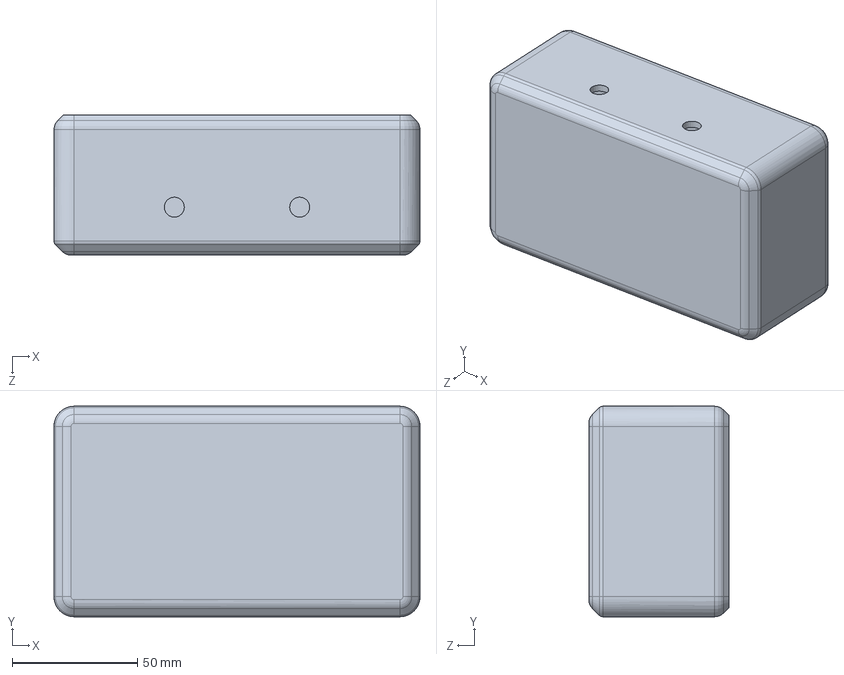
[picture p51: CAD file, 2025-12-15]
Enclosure Design/Part Files/ENCLOSURE_MASTER.SLDPRT
146.0 x 84.0 x 56.0 mm

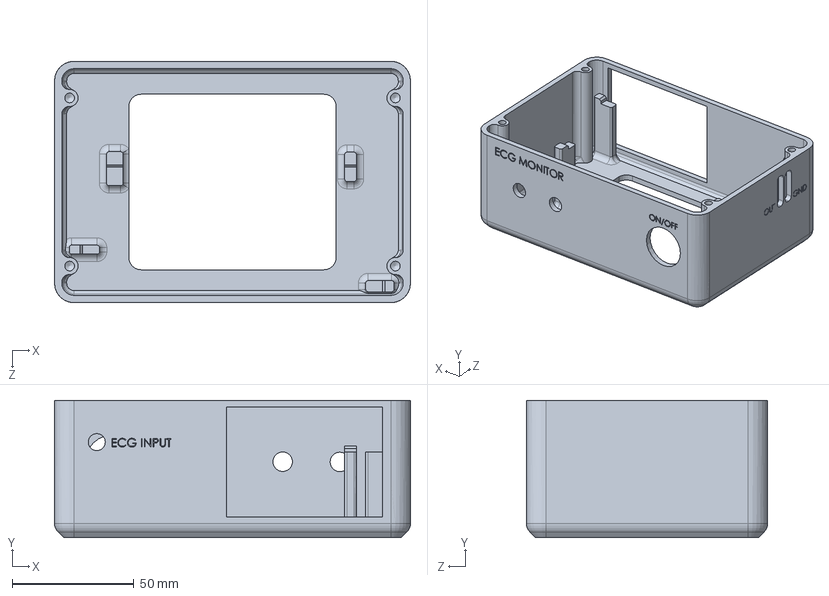
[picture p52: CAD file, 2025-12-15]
Enclosure Design/Part Files/BOTTOM.SLDPRT
146.0 x 56.2 x 99.0 mm

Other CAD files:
Enclosure Design/Part Files/enclosure rect.SLDPRT
Enclosure Design/Part Files/BOTTOM_GROVE.SLDPRT
Enclosure Design/Part Files/GROOVE.SLDPRT
Enclosure Design/Part Files/HORIZONTAL_BAR_2.SLDPRT
Enclosure Design/Part Files/HORIZONTAL_BAR_1.SLDPRT
Enclosure Design/Part Files/BAR_2.SLDPRT
Enclosure Design/Part Files/BAR_1.SLDPRT

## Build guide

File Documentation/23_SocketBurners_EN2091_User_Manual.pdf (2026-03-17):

# PulseView – Quick start Guide

v. 2025-1, made by Socket_Burners

Ayanaja N.B.G.M.(230065H), Imbulpitiya B.N.(230259G),

### Imaduwage O.N.H.(230258D), Ilankoon I.M.M.K.B(230256U)

### December 13, 2025

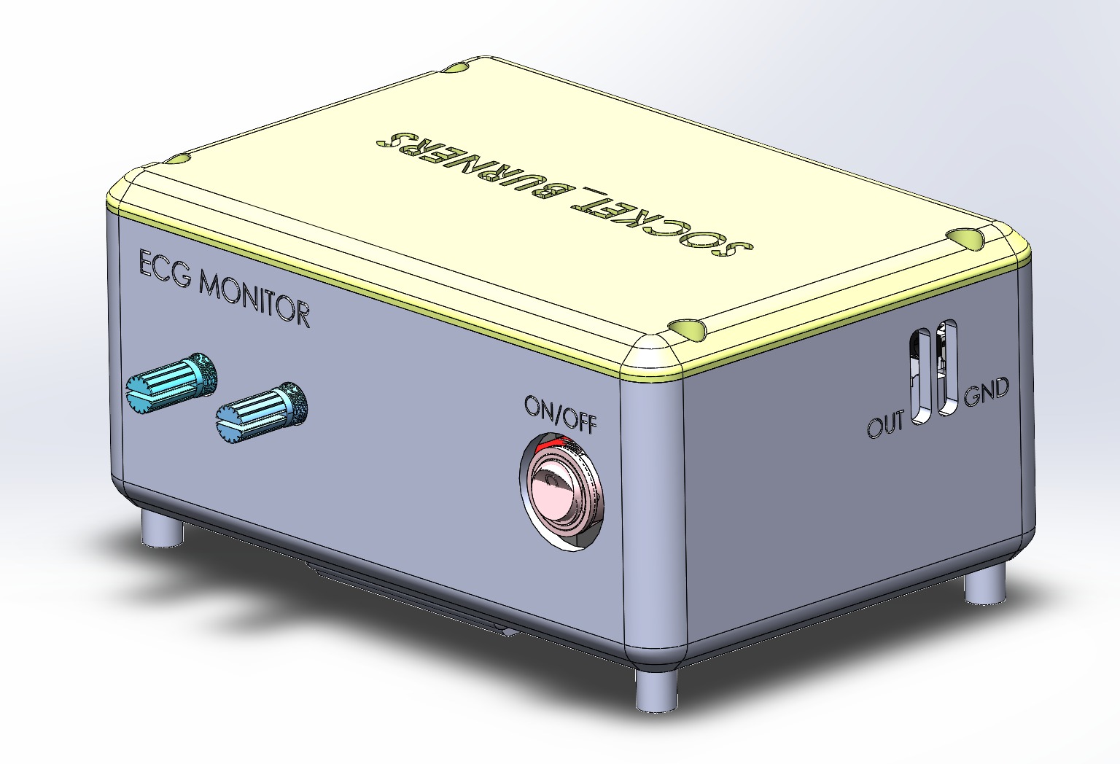
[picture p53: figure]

Introduction

PulseView is a portable, battery-powered ECG viewing device designed for clear, real-time visualization of heart electrical activity. It uses a simple three-electrode configuration (RA, LA, RL) and a fully analog signal-conditioning chain to capture clean, high-fidelity cardiac signals without the need for complex digital processing. The device amplifies and stabilizes the micro-volt ECG signal using an instrumentation amplifier, while a Right-Leg Drive circuit actively suppresses common-mode noise for improved clarity. The signal is then refined through a sequence of analog filters, including low-pass filtering to reduce baseline drift, high-pass filtering to suppress muscle-related high-frequency interference, and a 50 Hz notch filter to eliminate ambient power-line noise. The resulting waveform can be observed directly on an oscilloscope or digitized via an ADC for display. PulseView offers a compact reliable solution for portable ECG monitoring for educational applications.

1

PulseView ECG Device | Page 1

## Contents

1 Device Overview | 2
2 Using PulseView Device | 3
3 Troubleshooting | 5
4 Technical Support Information | 7
5 Regulatory Information | 9

PulseView ECG Device | Page 2

## 1 Device Overview

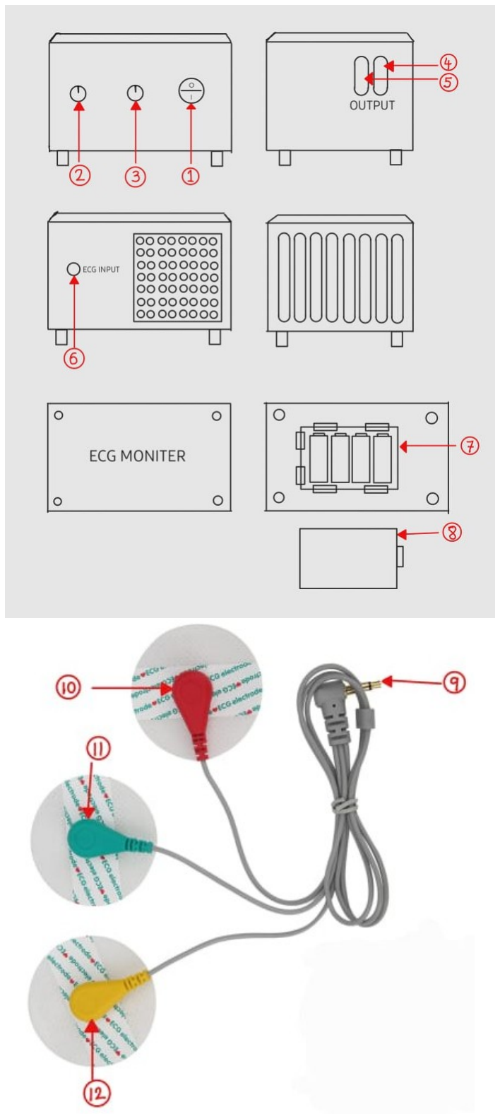
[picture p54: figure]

Figure 1: PulseView Device.

PulseView ECG Device | Page 3

Table 1: Device Components

No. Component Description
1 | On/Off switch
2 | Instrumentation amplifier gain adjustment knob
3 | Notch filter adjustment knob
4 | Output signal port
5 | Output ground port
6 | Auxiliary input for ECG lead
7 | Battery compartment
8 | Battery cover
9 | Auxiliary port of the ECG lead
10 | Red lead (Left arm)
11 | Green lead (Right arm)
12 | Yellow lead (Right leg)

## 2 Using PulseView Device

### 2.1 Providing Power

The device is powered by four 18650-type 3.7 V Li-Ion batteries. To insert the batteries, slide open the bottom cover and place the batteries according to the polarity markings on the casing. After closing the cover, toggle the main On/Off switch to power on the device.

### 2.2 Providing Input

Connect the auxiliary port of the ECG lead to the ECG input [(6) in Figure 1]. Then attach the three electrodes to the patient’s chest according to Figure 2.

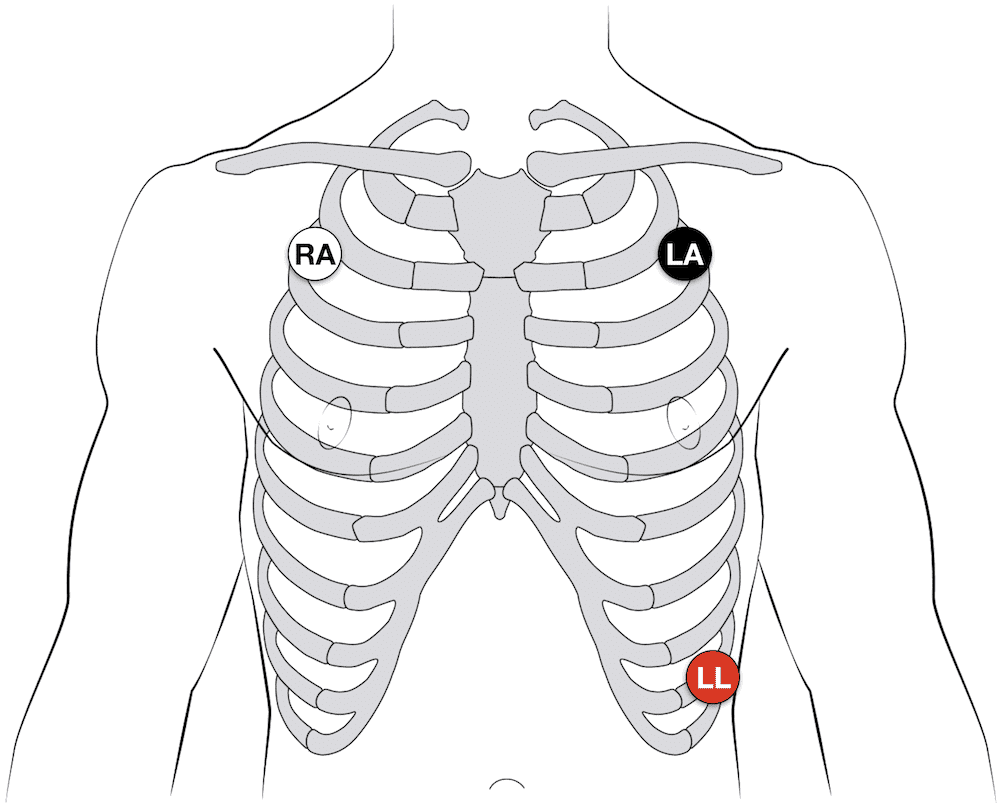
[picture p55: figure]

Figure 2: Electrode Placement on the chest

PulseView ECG Device | Page 4

### 2.3 Adjusting the Signal

The instrumentation amplifier gain adjustment knob [(2) in Figure 1] can be used to control the signal amplitude, while the notch filter adjustment knob [(3) in Figure 1] is used to reduce power-line interference and improve overall signal clarity.

### 2.4 Maintenance and Care

### 2.4.1 Cleaning the Device

- Ensure the device is powered off and disconnected from any external equipment before cleaning.
- Wipe the exterior surfaces with a soft, lint-free cloth slightly dampened with water or a mild, non-abrasive detergent.
- Do not use alcohol, solvents, or aerosol cleaners, as they may damage the enclosure or internal components.
- Avoid allowing moisture to enter any openings, connectors, or switches.

### 2.4.2 Electrode and Cable Care

- Inspect electrode cables regularly for signs of wear, cracking, or loose connectors. Replace immediately if damaged.
- Clean reusable electrodes (if applicable) using a damp cloth. Allow them to dry fully before use.
- Store electrodes with their protective caps or covers to prevent contamination or bending of contact surfaces.
- When disconnecting leads, pull from the connector, not the cable, to prevent internal wire damage.

### 2.4.3 Battery Care

- Use only the recommended battery type specified for PulseView.
- Remove the battery if the device will not be used for an extended period to prevent leakage or corrosion.
- Avoid exposing the device or battery to excessive heat, direct sunlight, or high humidity.
- If battery performance noticeably decreases, replace it with a new unit of the same specification.

PulseView ECG Device | Page 5

### 2.4.4 Storage Conditions

- Store the device in a cool, dry place, away from dust and direct sunlight.
- Recommended storage temperature: 10°C–35°C.
- Keep the device away from strong magnetic fields, heavy vibration, and moisture.
- Before long-term storage, clean the device and remove the battery.

### 2.4.5 Handling and Usage Guidelines

- Avoid dropping, striking, or applying excessive pressure to the device.
- Do not attempt to open or modify the internal circuitry; this may void the warranty and affect performance.
- Keep the device away from liquids and conductive materials.
- Handle the device by its body and connectors, not by attached cables.

## 3 Troubleshooting

The following outlines common issues encountered during operation of the PulseView ECG device and provides recommended corrective actions. If a problem persists after performing these checks, discontinue use and contact technical support.

### 3.1 No Signal Displayed

Possible Causes:

- Electrodes not properly attached
- Lead cables disconnected or damaged
- Battery fully depleted
- Loose oscilloscope or ADC connection

Solutions:

- Ensure RA, LA, and RL electrodes are firmly attached to clean, dry skin
- Verify all cables are fully inserted and undamaged
- Replace or recharge the batteries
- Check that the output is correctly connected to the oscilloscope or display module
- Reset the device and restart measurement

PulseView ECG Device | Page 6

### 3.2 Excessive Noise or Unstable Waveform

Possible Causes:

- Device not tuned properly
- Poor electrode contact or dried gel
- Movement artifacts from patient motion
- Nearby electronic interference
- Damaged or loose cables
- Insufficient grounding or RL electrode not connected

Solutions:

- Adjust the knobs (especially the Q-Factor) to sharpen the signal
- Reapply or reposition electrodes; clean skin before attachment
- Keep the subject relaxed and still during measurement
- Move the device away from AC power sources, motors, or fluorescent lights
- Inspect and replace damaged cables
- Ensure the RL (Right Leg Drive) electrode is properly connected to enable noise cancellation

### 3.3 Weak or Distorted ECG Waveform

Possible Causes:

- Device not tuned properly
- Incorrect electrode placement
- Baseline drift caused by poor skin contact or movement
- Filters not functioning as expected
- Battery voltage too low for proper amplifier operation

Solutions:

- Tune the device to increase the gain and sharpen the signal
- Confirm electrode placement (RA, LA, RL)
- Improve skin preparation (clean and dry before attaching electrodes)
- Replace the battery and retest

PulseView ECG Device | Page 7

### 3.4 Device Not Powering On

Possible Causes:

- Battery is dead or improperly inserted
- Power switch fault
- Internal wiring issue or blown fuse (if applicable)

Solutions:

- Replace the battery with a fresh one
- Ensure the battery is inserted with correct polarity
- Toggle the power switch several times to confirm operation
- If the device still does not power on, contact support — do not attempt internal repairs

## 4 Technical Support Information

If you require assistance with your PulseView device, our technical support team is available to help diagnose issues, provide usage guidance, and arrange repairs when necessary. Please review the troubleshooting section before contacting support, as many common issues can be resolved quickly.

### 4.1 Customer Support Contact

For questions, general assistance, or technical issues, please contact:

- Email: support@pulseview.com
- Phone: +94-772455800
- Website: www.pulseview.com/support

Support is available Monday–Friday, 9:00–17:00 (local time), excluding public holidays.

PulseView ECG Device | Page 8

### 4.2 Warranty Information

PulseView is covered by a limited warranty that protects against defects in materials and workmanship under normal use.
Warranty Period: 12 months from the date of purchase.
Coverage Includes:
- Internal electronic components
- Manufacturing defects
- Early component failure
Not Covered:
- Physical damage due to misuse, impact, or improper handling
- Damage caused by unauthorized modifications or repairs
- Normal wear of electrodes, cables, or consumable accessories
- Damage resulting from moisture, excessive heat, or improper storage Proof of purchase is required for warranty service.

### 4.3 Repair and Service Procedures

If your device requires service:

1. Contact technical support to describe the issue.
2. Complete basic diagnostics as instructed by support staff.
3. If repair is required, you will receive instructions for shipping or delivering the device to an authorized service center.
4. After inspection, you will be notified of warranty approval or estimated repair costs and turnaround time.
5. Devices approved under warranty will be repaired or replaced at no cost unless conditions invalidate coverage.
Do not attempt to open or repair the device yourself, as this may cause further damage and void the warranty.

### 4.4 Authorized Service Centers

Service and repairs are handled only by certified facilities to ensure safety and performance standards.

- Primary Service Center:
PulseView Technical Service Unit
Metro Street,
Colombo

Additional service locations may be listed on our website.

PulseView ECG Device | Page 9

### 4.5 Returns & Replacement Policy

If the device was purchased directly from our company or an authorized distributor:

- Returns are accepted within 30 days of purchase if the product is unused and in original condition.
- A replacement unit may be issued if the device is found defective upon arrival.
- Shipping instructions and return authorization will be provided by support.

## 5 Regulatory Information

PulseView is designed as a low-risk electrocardiography viewing device. The following regulatory information is provided to help users understand the device’s intended use and applicable requirements in regions where medical regulations apply.

### 5.1 Medical Device Status

PulseView is intended for basic ECG monitoring and educational use. It is not intended for clinical diagnosis, patient treatment, or life-support applications unless it has been specifically cleared or approved by the appropriate regulatory authority.
Depending on the region, the device may fall under:
- United States (FDA): Classified as a Class I medical device (exempt from premarket notification) when used for general ECG monitoring. Diagnostic use may require FDA 510(k) clearance.
- European Union (EU MDR): Typically considered a Class I device for non-diagnostic monitoring. Diagnostic use requires conformity assessment and CE marking.
- Other Regions: Local regulatory agencies may classify the device differently based on intended use.

Users must comply with local regulations regarding operation and distribution.

### 5.2 Intended Use Notice

- The device is intended for recording and viewing ECG waveforms from surface electrodes.
- It is not designed to replace professional medical diagnostic equipment.
- Interpretation of ECG signals should be performed only by trained personnel where diagnostic use is permitted.

PulseView ECG Device | Page 10

### 5.3 Regulatory Warnings

- Do not modify the hardware or circuitry. Alterations may invalidate regulatory compliance.
- Use only approved accessories and components.
- When used in clinical or educational environments, follow all required safety and electrical standards for the facility.

### 5.4 Certification Documentation

A formal Regulatory Compliance Statement or Declaration of Conformity may be provided upon request. Users requiring documentation or regulatory assistance should contact technical support.

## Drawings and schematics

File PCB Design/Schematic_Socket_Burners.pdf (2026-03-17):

# Power & ECG Input

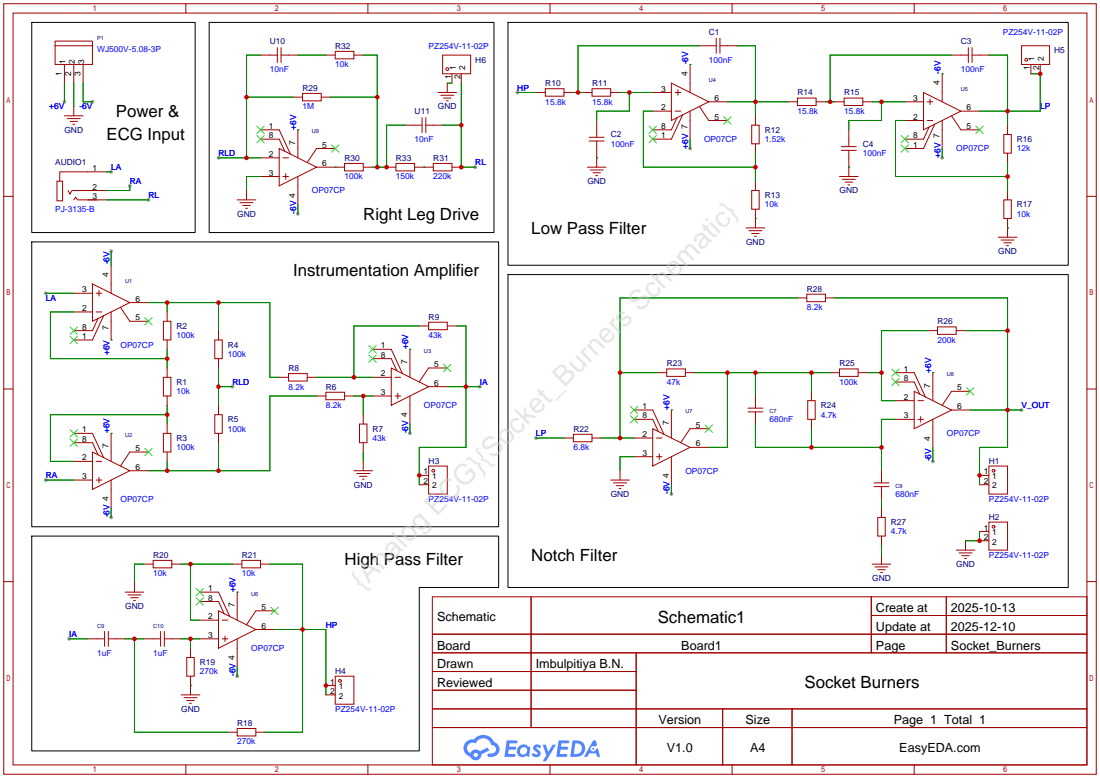
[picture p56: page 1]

Schematic | Schematic1 | Create at | 2025-10-13

Update at | 2025-12-10

Board | Board1 | Page | Socket_Burners
Drawn | Imbulpitiya B.N. | Socket Burners
Reviewed

Version | Size | Page 1 Total 1
V1.0 | A4 | EasyEDA.com

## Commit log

2025-09-04 Added Notch filter
2025-09-04 added plots
    [Gain Vs Frequncy.xlsx]
2025-09-07 add the low-pass filter
    [ecg_with_time.csv]
2025-09-18 Simulation file with all filters
    sim file with all filters, lacks the Right Leg Drive and Power Supply circuit
2025-09-19 improved final simulation
    added the right leg drive and opamp power supply
    formatted the simulation file
    [ecg_with_time.csv]
2025-12-15 Clarify amplification specification in README
    Updated the amplification specification to include resistors and capacitors.
2025-12-15 Revise README for 3-Lead ECG Monitor project
    Expanded project details, specifications, and features for the 3-lead ECG monitor. Added sections on signal processing, circuit design, hardware implementation, and testing results.
2025-12-15 Revise README by removing Table of Contents and Circuit Design
    Removed the Table of Contents and Circuit Design sections from the README.
2025-12-15 Update PCB design software
2026-03-17 Docs and PCB
    [BOM_Socket_Burners.xlsx, Socket_Burners.pcbdoc, Socket_Burners.schdoc]
2026-03-17 Update Final Assembly.JPG
